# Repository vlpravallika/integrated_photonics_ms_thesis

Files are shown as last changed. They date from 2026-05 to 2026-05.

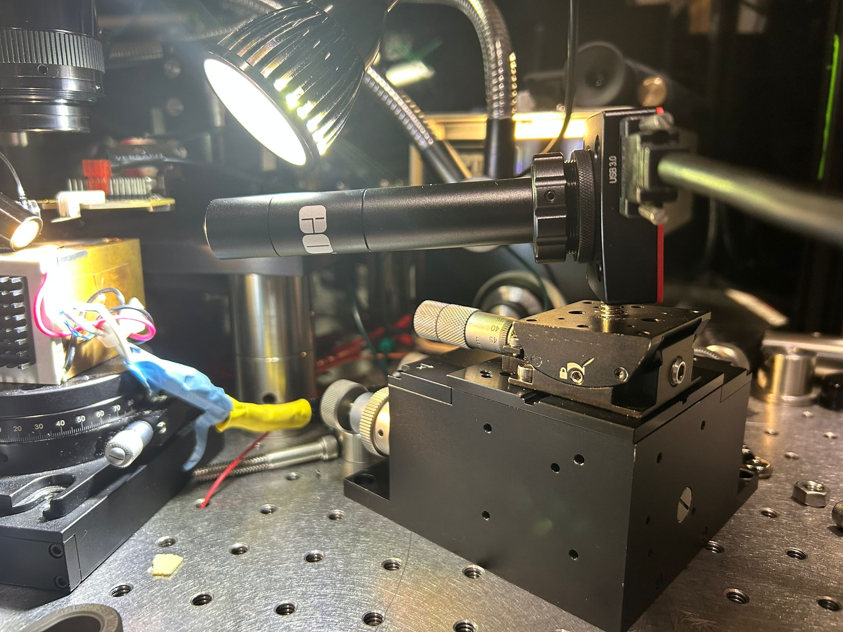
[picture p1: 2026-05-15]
Project_1_On_Chip_Detection/Images/setup_lens_camera_nanomax_goniometer.jpeg

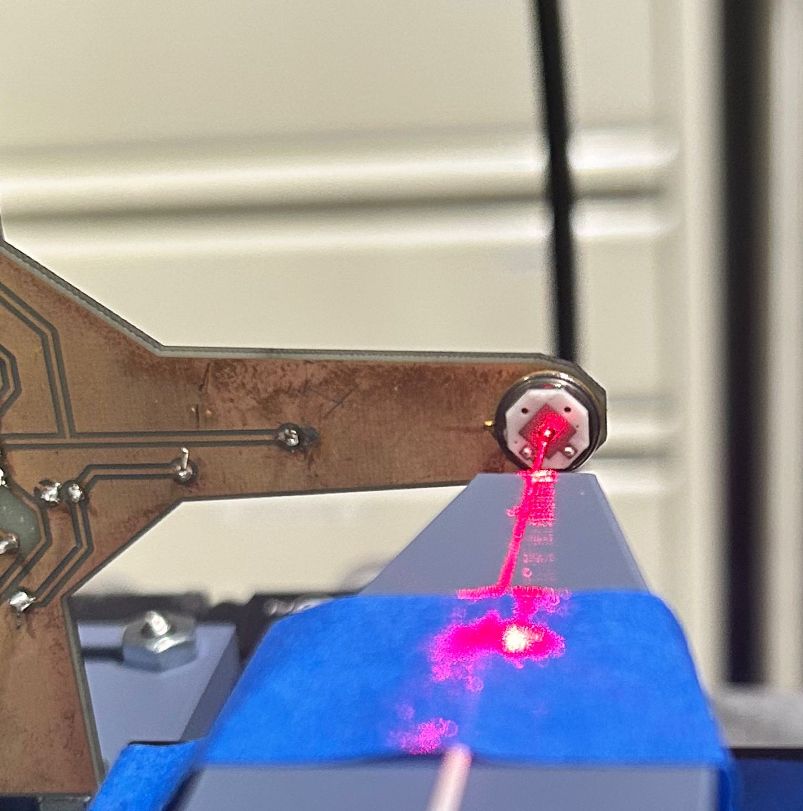
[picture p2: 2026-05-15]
Project_1_On_Chip_Detection/Images/setup_red_light_zoom.jpeg

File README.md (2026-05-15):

# Device Exploration for On-Chip Detection on Lithium Niobate and Amplification on Silicon for Scalable Integrated Photonics

**Vemparala Lakshmi Pravallika**  
B.Tech., Indian Institute of Technology Bombay (2024)  

Program in Media Arts and Sciences, School of Architecture and Planning  
Massachusetts Institute of Technology  

Master of Science in Media Arts and Sciences · submitted **15 May 2026**  

**Thesis supervisor:** Dirk Englund — Professor of Electrical Engineering and AI + Decision-making, MIT EECS  
**Committee:** Dirk Englund, Joseph Paradiso, Jelena Notaros  

**Committee certification page title (longer variant):** *Device Exploration for High-Efficiency On-Chip Detection in TFLN and Heterogeneous Gain Integration on Si for Scalable Integrated Photonics*  

The **citation copy** of the thesis is the **MIT-submitted document** (Libraries / program deposit). This Git directory holds **artifacts only** (CAD interchange, notebooks, code, CSV measurements).

---

## Abstract (as submitted)

Passive photonic integrated circuits excel at routing and modulating light, but generation and detection still rely on heterogeneous integration of foreign active materials. Bonding, epitaxy, flip-chip, and micro-transfer printing dominate how industry and research labs attach III–V detectors, amplifiers, and lasers to substrate hosts. An important bottleneck is the active–passive interface: coupling efficiency, alignment, and yield.

This thesis contributes two complementary demonstrations on leading passive platforms. Project 1 targets efficient telecom-band photodetection on thin-film lithium niobate. Lithographic adiabatic tapers to an absorber are the established route; here a doubly-clamped rib waveguide is selectively underetched and buckled so that a mechanical air gap drives the same adiabatic transition. Modeling predicts waveguide-to-absorber coupling near unity and total quantum efficiency near ninety-six percent for the coupled-mode design. A fiber-coupled test bench was built to characterize transmission and to separate the evanescent path from parasitic paths; a successor layout will suppress the dominant parasitic channel by geometry.

Project 2 targets optical gain on silicon using micro-transfer printing: a GaAs quantum-dot nanobeam with a 1D photonic-crystal cavity is placed on a silicon taper so that the signal transfers vertically to the III–V and is amplified by donor material. The workflow from donor release through stamp alignment and confocal pump delivery was implemented end-to-end, with several chiplets aligned within the taper tolerance for follow-on characterization.

Taken together, the work advances reusable recipes for high-efficiency detection on TFLN and compact gain on silicon spanning coherent links, switches, sensing, and integrated nonlinear and quantum photonics.

---

## What this repository contains

This tree is the **working artifact bundle** for the thesis hardware chapters: **SolidWorks / STEP digital twins** for both benches, **GDSFactory** mask notebooks, **COMSOL** project locks (models may be kept locally), **Tidy3D** mode notebooks and scripts, **Chip 1** detector-linearity checks, and **Chip 2** loopback **wavelength–power CSV archives** plus Python reduction and plotting.

There is **no separate folder named `transmission results`**: the **transmission sweep results** are the **`sweep_*.csv`** files (and derived **`summary_*.csv`**) under **`Chip 2 measurements/sweep 16 waveguides transmission/`**.

---

## Indexed layout (files that exist in this directory)

### `on chip detection setup solidworks model/`

**Project 1** mechanical **digital twin** geometry in neutral **STEP/STP** interchange (import into SolidWorks or any MCAD viewer). This is the same class of assembly the thesis documents in **§3.2.1** and **Fig. 3.4** (fiber-coupled detector bench with horizontal side-view imaging, clearance checks before 3D-printed fixtures).

| File | Role |
|---|---|
| `fiber array holder 15_01.STEP` | Custom **fiber-array holder** solid exported from SolidWorks (15 Jan revision in filename). |
| `Newport-TSX-1D.stp` | Newport **TSX-1D** linear stage vendor solid. |
| `B1818F-Step.step` | Thorlabs **B1818F** breadboard / plate geometry. |
| `MAX313D-Step.step` | Thorlabs **MAX313D** mount solid. |
| `TTR001-Step.step` | Thorlabs **TTR001** rotation mount solid. |
| `GPXL1-Step.step` | Thorlabs **GPXL1** goniometric stage solid. |
| `PR01-Step.step` | Thorlabs **PR01** cage plate solid. |
| `HFV002-Step.step` | Thorlabs **HFV002** vertical translation stage solid. |
| `CS165MU-Step.step` | Thorlabs **CS165MU** post / pedestal solid. |
| `step_63744.step` | Additional interchange solid from the same export set (SolidWorks default `step_*.step` naming). |

### `Topchip gain integration setup digital twin/`

| File | Role |
|---|---|
| `step_88206.step` | **Project 2** bench **STEP** export: silicon host with **dual edge-coupled fiber stacks** and **vertical confocal microscope** access as laid out in **§3.4.4–3.4.5** of the thesis (stamp alignment and pump delivery geometry). |

### `GDS/`

| File | Role |
|---|---|
| `loopback chip iteration 4.ipynb` | **Primary** **GDSFactory** notebook (generic PDK): **0.8 µm** strip waveguide, **127 µm** facet pitch, Euler **U-turn** radius `(PITCH/2)−5.8` µm, long routing straights, **`ETCH_LENGTHS` × `ETCH_WIDTHS` × `ETCH_GAPS`** etch-window sweep, layer pair `(1,0)` waveguide / `(2,0)` box. This is the **Chip 2** loopback mask lineage behind **Fig. 3.11** in the thesis. |
| `loopback chip iteration 3.ipynb` | **Earlier** loopback notebook (`repeats = 7`, **5000 µm** straight sections, etch lengths up to **2500 µm**, boolean / `LayerStack` tooling) retained for iteration history. |
| `bend_radius_analysis.ipynb` | **Tidy3D**-invoking bend / propagation study notebook (see notebook for exact solver calls and warnings). Informs Euler bend radius choices in the loopback notebooks. |

### `COMSOL Sim/`

| File | Role |
|---|---|
| `strip waveguide compressed.mph.lock` | Lock file for the **strip waveguide** COMSOL model (`strip waveguide compressed.mph` when saved locally). |
| `taper waveguide edge.mph.lock` | Lock file for the **taper / facet-edge** waveguide model (`taper waveguide edge.mph` when saved locally). |

Only **`.mph.lock`** files are present in this snapshot; the binary **`.mph`** models are usually excluded from Git for size. Re-open the corresponding `.mph` in COMSOL on a machine that has the full file.

### `Mode simulations/`

Eigenmode and overlap work for the **LNOI rib** cross section at **1550 nm** scale (thesis **Fig. 3.2** class: Tidy3D FDE rib mode).

| Path | Role |
|---|---|
| `ln_rib_mode_overlap.ipynb` | Notebook pipeline for **rib eigenmodes** and **overlap integrals** with a cleaved **SMF-28** Gaussian (**MFD = 10.4 µm**). |
| `edge_coupler.ipynb` | Notebook for **edge-coupler** field / coupling studies. |
| `rib waveguide modes.py` | Standalone **Tidy3D** `ModeSolver` script: **10 µm** SiO₂ underclad, **0.30 µm** LN film, **0.10 µm** slab, **0.20 µm** rib height, **0.80 µm** rib top width, **5.6 µm** bottom width; computes mode fields and **power overlap** with fiber mode. |
| `.vscode/settings.json` | Workspace editor settings used while developing these notebooks. |
| `build/log/.wsport.log` | Tool-generated log from a local solve / IDE session. |

### `Chip 1/`

| File | Role |
|---|---|
| `characterisation of detector comparison.py` | **Capped vs. uncapped** photoreceiver comparison: hard-coded **`power_dbm_*`** vs **`voltage_v_*`** arrays, plots **dBm** and **µW** vs voltage and inferred **photocurrent**; writes **`compare_dBm_vs_voltage.png`**, **`compare_uW_vs_voltage.png`**, **`compare_current_vs_voltage.png`** in the current working directory when run. Supports the **TIA / saturation** discussion around **Fig. 3.14** bench checkout. |

### `Chip 2 measurements/`

**Thesis linkage:** **§3.3.5** (measurement protocol), **§4.1.2–4.1.4** (contamination, operating wavelength, 2D free-space model). **Chip 2** has **25** designed loopbacks; **16** cleaved to viable facets (**§3.3.5** text). **Configuration 1** = angled facets; **Configuration 2** = parallel facets (**§3.3.5**). Sweeps run **1480–1600 nm**, **0 dBm** input; **~1595 nm** adopted as common operating point (**§4.1.3**, **Fig. 4.2**).

| Path | Role |
|---|---|
| `sweep 16 waveguides transmission/sweep_*.csv` | Raw **wavelength sweep** logs: columns include **`wavelength_nm`** and **`power_dBm`** (after instrument export). Filename grammar after cleanup: `sweep_<structure>_<YYYYMMDD>_<HHMMSS>.csv` for **Configuration 1** runs and `sweep_<structure>_p_<YYYYMMDD>_<HHMMSS>.csv` when `_p_` marks **Configuration 2** (“parallel facets”) reruns. |
| `sweep 16 waveguides transmission/summary_selected.csv` | Per-structure, per-orientation **max power** table produced by **`transmission_calculation.py`**. |
| `sweep 16 waveguides transmission/summary_maxima_selected.csv` | Alternate / intermediate maxima summary from the same script family. |
| `sweep 16 waveguides transmission/summary_maxima.csv` | Broader maxima table prior to orientation filtering (same analysis lineage). |
| `sweep 16 waveguides transmission/transmission_calculation.py` | **(1)** Regex-based batch **rename** of `sweep_*.csv` to the canonical patterns above (collision-safe). **(2)** **pandas**/**numpy** pass: filters structures **`{3,7,8,9,10}`**, finds **argmax** of `power_dBm`, deduplicates by structure+orientation, writes **`summary_selected.csv`** and **`wavelength_vs_structure_selected.png`**. |
| `transmission variation in fiber x.py` | Standalone **matplotlib** plots of **detector voltage vs. fiber \(x\)** (µm) from embedded arrays: raw trace, min–max scaled, and **20·log₁₀(V/Vmax)** dB scale—used for **lateral alignment** sweeps in the same measurement campaign as **§4.1.4**. |
| `Plots/Transmisison values for all 16 loopbacks comparison.py` | **Agg** backend: plots **all 16** structures’ **dBm** values at **1595 nm**, **0 dBm** input for **Case 1** vs **Case 2** arrays (same physical content as **Configuration 1** vs **2** in the thesis), highlights structures **3,7,8,9,10**, draws **−28 dBm** and **−65 dBm** reference lines. **You must edit `out_path`** inside the script before saving figures on a new machine. |

### `README.md`

This file.

---

## How measurements map to thesis language

- **Thesis:** **Configuration 1** (angled interfaces) vs **Configuration 2** (parallel interfaces).  
- **Python in this repo:** often labeled **Case 1** / **Case 2** in comments and plot legends.

---

## Dependencies (by component)

| Component | Typical stack |
|---|---|
| `GDS/*.ipynb` | **Python 3.10+**, **`gdsfactory`**, Jupyter |
| `Mode simulations/*` | **`tidy3d`**, **`numpy`**, **`matplotlib`**, Jupyter |
| `COMSOL Sim` | **COMSOL Multiphysics** (version matched to your `.mph`) |
| `Chip 2 measurements/*.py` | **`numpy`**, **`matplotlib`**; **`transmission_calculation.py`** analysis cell needs **`pandas`** |
| CAD | Any STEP/STP-capable viewer (SolidWorks, Onshape, FreeCAD) |

---

## Suggested reproduction order

1. Open STEP files in **`on chip detection setup solidworks model/`** and **`Topchip gain integration setup digital twin/`** to recover full 3D clearance context (**Fig. 3.4** and Project 2 bench figures).  
2. Run **`GDS/loopback chip iteration 4.ipynb`**, then compare against **`loopback chip iteration 3.ipynb`** for design deltas.  
3. Run **`bend_radius_analysis.ipynb`** if updating bend radii before a mask rerun.  
4. Execute **`Mode simulations/rib waveguide modes.py`** or the notebooks after configuring **Tidy3D** credentials.  
5. Open COMSOL **`.mph`** files that pair with the two **`.mph.lock`** names (local machine).  
6. From **`Chip 2 measurements/sweep 16 waveguides transmission/`**, run **`transmission_calculation.py`** (rename pass only when ingesting new raw sweeps), then run the **`Plots/`** script after fixing paths.

---

## Version control hygiene (recommended)

Add to **`.gitignore`** if you expand commits: `*.mph.lock`, `**/.vscode/`, `**/build/`, large `*.mph`, and any regenerated **`compare_*.png`** / **`transmission_vs_structure.png`** outputs if you do not want binaries in history.

---

## License

Thesis text and figures: © **2026** Vemparala Lakshmi Pravallika (subject to MIT thesis deposit terms). **Vendor STEP** models remain property of their respective suppliers. **Tidy3D**, **COMSOL**, **gdsfactory**, and Python packages follow their own licenses.

---

## Contact

Use the correspondence channels listed in the submitted thesis front matter.

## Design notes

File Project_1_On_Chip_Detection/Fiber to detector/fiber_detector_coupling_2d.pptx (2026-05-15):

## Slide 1

Fiber-to-Detector 2D Coupling: Model & Concepts

Geometry
SMF-28 fiber emits along +x; detector active face points -z (downward)
Only diverging rays from the Gaussian tail reach the detector
2D cross-section in the x-z plane; detector length = 1 mm
Factors in the Model
1. Gaussian beam angular profile G(th) = exp(-2 th^2 / th0^2)
2. Snell refraction at fiber exit (n_core > n_air -> beam widens)
3. Fresnel transmission at fiber exit (glass -> air interface)
4. Geometric angular aperture (which angles hit the detector)
5. Fresnel transmission at detector (air -> InGaAs, angle-dependent)
Coupling Fraction
eta = Integral of [ G * T_fiber * T_detector ] over detector angles
divided by total Gaussian power in forward half-space
Each factor is evaluated at every angle — not a single average

Dominant Loss Mechanisms
1. Gaussian falloff (dominant)
Intensity drops exponentially off-axis
At th0: 13.5% of peak
At 2*th0: 0.03% of peak
2. Fresnel loss at detector
High index mismatch (n=1 -> n=3.5)
Near-grazing incidence in this geometry
Transmittance 40-60% at typical angles
3. Fresnel loss at fiber exit
Glass-to-air reflection (~3.6%)
Relatively minor compared to above two

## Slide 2

How Position Affects Coupling (x, z Dependence)

Vertical distance z (dominant)
Larger z -> steeper angle from fiber axis
Steeper angle -> deeper into Gaussian tail -> exponentially less power
Also: steeper angle -> more grazing on detector -> higher Fresnel loss
z is the single most critical parameter
Horizontal distance x
Larger x -> ray angle to detector center decreases (closer to axis)
-> more Gaussian intensity available
But also: larger x -> detector subtends smaller angular range
-> captures less of the beam
Trade-off: optimal x exists for each z
Combined behavior
Best coupling at small z and moderate x
Coupling falls off exponentially with z, logarithmically with x mismatch

Physical Picture
The Gaussian beam is a narrow cone:
most power within ~5 deg of axis.
Moving detector UP (larger z):
-> requires light at steeper angles
-> exponential intensity drop
-> worse Fresnel at detector
Moving detector RIGHT (larger x):
-> shallower angle (more intensity)
-> but narrower angular aperture
-> net effect: diminishing returns
Best 2D coupling: ~4-5%
(-13 to -15 dBm for 0 dBm input)
at z ~ 100-200 um, x ~ 2000-4000 um

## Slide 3

Detector & Waveguide Placement: Safe from Stray Light

Placement Strategy
All waveguides and detector must lie outside the 2*th0 emission cone
2*th0 = 10.9 deg contains 99.97% of beam power (only 0.03% beyond)
Additional 500 um safety margin in lateral (y) direction
Waveguide Loopback
Lateral shift y = cone height at arm end + 500 um margin
Arm length 7000 um | pitch 127 um | all arms above the cone
Detector (1 mm diameter, parallel to chip)
Placed at min. clearance position: 500 um inside WG end, 500 um above cone
Angle from fiber axis to detector center: 15.1 deg >> 2*th0 = 10.9 deg
Gaussian intensity at detector: < 10^-7 of peak
Coupled power: < -80 dBm (effectively zero stray light)
Verification Summary
Detector center well outside beam cone (15 deg vs 11 deg boundary)
Waveguides entirely beyond 2*th0 + 500 um margin
No fiber stray light interferes with detector or waveguide etch region
Safe for detector operation without additional shielding

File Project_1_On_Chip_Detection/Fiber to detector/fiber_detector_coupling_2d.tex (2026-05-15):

% ======================================================================
% Paste this section into your existing document.
% Required packages (add to your preamble if not already present):
%   \usepackage{amsmath,amssymb}
%   \usepackage{physics}        % for \dd
%   \usepackage{siunitx}        % for SI units
%   \usepackage{booktabs}       % for tables
%   \usepackage{enumitem}       % for custom lists
% ======================================================================

\section{2D Gaussian Beam Coupling: SMF-28 Fibre to Side-Facing InGaAs Detector}

% ----------------------------------------------------------------------
\subsection{Problem Geometry}
% ----------------------------------------------------------------------

Consider a single-mode fibre (Corning SMF-28) with its cleaved end-face
oriented so that the fibre axis is horizontal (the $+x$~direction).
An InGaAs photodetector of length $d = \SI{1}{\milli\metre}$ is placed
above the fibre tip with its active surface facing \emph{vertically
downward} (the $-z$~direction).  The detector centre is located at
horizontal distance~$x_c$ and vertical distance~$z_\mathrm{det}$ from
the fibre tip.

In this 2D analysis (cross-section in the $xz$-plane), the fibre emits
a Gaussian beam into the forward half-space.  Only a small fraction of
this light propagates at a steep enough angle to intercept the detector,
and that fraction is further reduced by Fresnel reflections at two
interfaces:
%
\begin{enumerate}[label=(\roman*)]
  \item the fibre end-face (glass $\to$ air), and
  \item the detector active surface (air $\to$ InGaAs).
\end{enumerate}

% ----------------------------------------------------------------------
\subsection{Key Parameters}
% ----------------------------------------------------------------------

\begin{center}
\begin{tabular}{@{}llll@{}}
\toprule
\textbf{Symbol} & \textbf{Description} & \textbf{Value} & \textbf{Unit} \\
\midrule
$\lambda$       & Free-space wavelength        & 1.550  & \si{\micro\metre} \\
$w_0$           & Beam waist (MFD/2)           & 5.2    & \si{\micro\metre} \\
$n_\text{core}$ & Fibre core index (@\SI{1550}{\nano\metre}) & 1.4682 & -- \\
$n_\text{air}$  & Air refractive index         & 1.0    & -- \\
$n_\text{det}$  & InGaAs detector index (@\SI{1550}{\nano\metre}) & 3.5 & -- \\
$d$             & Detector length              & 1.0    & \si{\milli\metre} \\
\bottomrule
\end{tabular}
\end{center}

\noindent
The mode-field diameter (MFD) of SMF-28 at \SI{1550}{\nano\metre} is
approximately \SI{10.4}{\micro\metre}, giving a beam waist
$w_0 = \text{MFD}/2 = \SI{5.2}{\micro\metre}$.

% ----------------------------------------------------------------------
\subsection{Gaussian Beam Divergence}
% ----------------------------------------------------------------------

\subsubsection{Divergence inside the fibre}

A Gaussian beam with waist $w_0$ propagating in a medium of refractive
index $n$ has a far-field $1/e^2$ half-angle divergence given by
%
\begin{equation}\label{eq:theta-fib}
  \theta_\text{fib}
  = \frac{\lambda}{\pi\, n_\text{core}\, w_0}.
\end{equation}
%
Substituting the values:
%
\begin{equation}
  \theta_\text{fib}
  = \frac{1.550 \times 10^{-6}}
         {\pi \times 1.4682 \times 5.2 \times 10^{-6}}
  \approx 0.0646~\text{rad}
  \approx 3.70^\circ.
\end{equation}

\subsubsection{Snell's refraction at the flat fibre end-face}
\label{sec:snell}

The fibre has a flat, cleaved end-face that acts as a planar dielectric
interface between the fibre core (index $n_\text{core}$) and air
(index $n_\text{air}$).  When a ray at angle $\theta_\text{fib}$
(measured from the fibre axis, i.e.\ the surface normal of the end-face)
exits the fibre, Snell's law governs the refracted angle:
%
\begin{equation}\label{eq:snell}
  \boxed{%
    n_\text{core}\,\sin\theta_\text{fib}
    = n_\text{air}\,\sin\theta_0
  }
\end{equation}
%
Since $n_\text{core} > n_\text{air}$, the refracted angle $\theta_0$
is \emph{larger} than $\theta_\text{fib}$: the beam fans out more
in air than it did inside the glass.  Solving for $\theta_0$:
%
\begin{equation}\label{eq:theta0}
  \theta_0
  = \arcsin\!\left(\frac{n_\text{core}}{n_\text{air}}
    \sin\theta_\text{fib}\right)
  = \arcsin\!\bigl(1.4682 \times \sin 3.70^\circ\bigr)
  \approx 5.44^\circ.
\end{equation}

\paragraph{Physical intuition.}
Light travels slower in glass (higher index) than in air.  At the flat
interface, the tangential component of the wavevector is conserved;
consequently the ray bends \emph{away} from the surface normal when
passing from a denser to a less dense medium.  The divergence
half-angle increases from $3.70^\circ$ to $5.44^\circ$.

% ----------------------------------------------------------------------
\subsection{Gaussian Angular Intensity Profile}
% ----------------------------------------------------------------------

In the far field, the angular intensity distribution of the Gaussian
beam (in air) is itself a Gaussian:
%
\begin{equation}\label{eq:gaussian}
  \boxed{%
    G(\theta) = \exp\!\left(-\frac{2\,\theta^2}{\theta_0^2}\right)
  }
\end{equation}
%
where $\theta$ is the angle of a given ray measured from the fibre axis,
and $\theta_0$ is the $1/e^2$ divergence half-angle in air
(Eq.~\ref{eq:theta0}).

\paragraph{Why the factor of 2?}
The electric \emph{field} amplitude falls as
$E(\theta) \propto \exp(-\theta^2/\theta_0^2)$.
Since intensity (power per unit angle in 2D) is proportional to
$|E|^2$, the intensity profile acquires twice the exponent:
$I \propto \exp(-2\theta^2/\theta_0^2)$.

\paragraph{Key values of $G(\theta)$:}
\begin{center}
\begin{tabular}{@{}lcc@{}}
\toprule
\textbf{Angle} & $G(\theta)$ & \textbf{Meaning} \\
\midrule
$\theta = 0$         & $1.000$        & On-axis (peak) \\
$\theta = \theta_0$  & $e^{-2} \approx 0.135$ & $1/e^2$ point; 13.5\% of peak \\
$\theta = 2\theta_0$ & $e^{-8} \approx 3.4\times10^{-4}$ & 0.03\% of peak \\
$\theta = 3\theta_0$ & $e^{-18}\approx 1.5\times10^{-8}$ & Essentially zero \\
\bottomrule
\end{tabular}
\end{center}

\noindent
The Gaussian drops \emph{extremely} rapidly with angle.  Since the
detector is placed off-axis (above the fibre), only rays in the tail of
the Gaussian distribution reach it, which is the dominant reason that
coupling is low in this side-fire geometry.

% ----------------------------------------------------------------------
\subsection{Fresnel Reflection and Transmission}
% ----------------------------------------------------------------------

At each dielectric interface, a fraction of the incident light is
reflected and the remainder is transmitted.  The reflectance depends on
the angle of incidence~$\theta_i$, the refractive indices $n_1$
(incident medium) and $n_2$ (transmitted medium), and the polarisation.

\subsubsection{Fresnel equations}

Using Snell's law to obtain the transmitted angle,
%
\begin{equation}
  \cos\theta_t = \sqrt{1 - \left(\frac{n_1}{n_2}\right)^2 \sin^2\theta_i},
\end{equation}
%
the amplitude reflection coefficients for \textbf{s}-polarisation (TE)
and \textbf{p}-polarisation (TM) are:
%
\begin{align}
  r_s &= \frac{n_1\cos\theta_i - n_2\cos\theta_t}
              {n_1\cos\theta_i + n_2\cos\theta_t},
  \label{eq:rs} \\[6pt]
  r_p &= \frac{n_2\cos\theta_i - n_1\cos\theta_t}
              {n_2\cos\theta_i + n_1\cos\theta_t}.
  \label{eq:rp}
\end{align}

\subsubsection{Power transmittance}

For unpolarised light (a reasonable assumption for a single-mode fibre
with no polarisation-maintaining structure), the average \textbf{power
transmittance} is:
%
\begin{equation}\label{eq:fresnel-T}
  \boxed{%
    T(\theta_i;\, n_1, n_2)
    = 1 - \frac{r_s^2 + r_p^2}{2}
  }
\end{equation}

\paragraph{Note on total internal reflection.}
When $n_1 > n_2$ (e.g.\ glass $\to$ air), if $\theta_i$ exceeds the
critical angle $\theta_c = \arcsin(n_2/n_1)$, the term under the
square root for $\cos\theta_t$ becomes negative, and \emph{all} light
is reflected ($T = 0$).  For the fibre exit face,
$\theta_c = \arcsin(1/1.4682) \approx 42.9^\circ$.  In practice, the
Gaussian beam has negligible power beyond $\sim\!3\theta_0 \approx
16^\circ$, so total internal reflection is not a concern.

\subsubsection{Interface 1: Fibre exit face (glass $\to$ air)}

At the fibre end-face, the incidence angle on the surface is $\theta$
(the same angle measured from the fibre/surface normal).  Thus:
%
\begin{equation}\label{eq:T-fib}
  T_\text{fib}(\theta) = T(\theta;\; n_\text{core},\; n_\text{air}).
\end{equation}
%
At normal incidence ($\theta = 0$):
%
\begin{equation}
  T_\text{fib}(0)
  = 1 - \left(\frac{n_\text{core} - n_\text{air}}
                    {n_\text{core} + n_\text{air}}\right)^{\!2}
  = 1 - \left(\frac{1.4682 - 1}{1.4682 + 1}\right)^{\!2}
  \approx 0.964.
\end{equation}
%
This means ${\sim}3.6\%$ of the on-axis power is reflected back into
the fibre at the exit face.

\subsubsection{Interface 2: Detector surface (air $\to$ InGaAs)}

The detector active surface is oriented vertically (facing downward,
perpendicular to the fibre axis).  A ray travelling at angle $\theta$
from the fibre axis strikes the detector surface at an incidence angle
of:
%
\begin{equation}\label{eq:det-angle}
  \theta_\text{inc,\,det} = \frac{\pi}{2} - \theta.
\end{equation}
%
This is because the detector normal is horizontal (along $-x$), while
the ray direction makes angle $\theta$ with the horizontal.
Therefore:
%
\begin{equation}\label{eq:T-det}
  T_\text{det}(\theta) = T\!\left(\frac{\pi}{2} - \theta;\;
    n_\text{air},\; n_\text{det}\right).
\end{equation}
%
\paragraph{Grazing incidence problem.}
For small $\theta$ (rays close to the fibre axis),
$\theta_\text{inc,\,det} \approx 90^\circ$, which is \emph{grazing
incidence}.  Fresnel reflectance approaches 100\% at grazing angles
for any dielectric interface.  Even at moderate angles, e.g.\
$\theta = 10^\circ$ gives $\theta_\text{inc,\,det} = 80^\circ$,
the transmittance is significantly reduced.

At normal incidence on the detector ($\theta_\text{inc,\,det} = 0$):
%
\begin{equation}
  T_\text{det}\big|_\text{normal}
  = 1 - \left(\frac{n_\text{air} - n_\text{det}}
                    {n_\text{air} + n_\text{det}}\right)^{\!2}
  = 1 - \left(\frac{1 - 3.5}{1 + 3.5}\right)^{\!2}
  \approx 0.691.
\end{equation}
%
Even at normal incidence, ${\sim}30.9\%$ of the light is reflected due
to the high refractive index of InGaAs.  At the typical incidence angles
in this geometry (\SIrange{75}{88}{\degree}), the transmittance drops
to roughly $40$--$60\%$.

% ----------------------------------------------------------------------
\subsection{Detector Geometry and Angular Limits}
% ----------------------------------------------------------------------

The detector of length $d$ is centred at horizontal position $x_c$
and height $z_\text{det}$.  Its left and right edges are at:
%
\begin{equation}
  x_L = x_c - \frac{d}{2}, \qquad x_R = x_c + \frac{d}{2}.
\end{equation}

From the fibre tip (the origin), the angle subtended by each edge is:
%
\begin{align}
  \theta_\text{min} &= \arctan\!\left(\frac{z_\text{det}}{x_R}\right),
  \label{eq:thmin} \\
  \theta_\text{max} &= \arctan\!\left(\frac{z_\text{det}}{x_L}\right).
  \label{eq:thmax}
\end{align}
%
These are the minimum and maximum angles (from the fibre axis) at which
a ray from the fibre tip can strike the detector.  The angular range
$[\theta_\text{min},\, \theta_\text{max}]$ defines the integration
limits for the coupling integral.

\paragraph{Edge cases.}
If $x_L \leq 0$ (detector extends behind the fibre tip), then
$\theta_\text{max} = \pi/2$.  If $x_R \leq 0$, the detector is
entirely behind the fibre and no forward-emitted light can reach it.

% ----------------------------------------------------------------------
\subsection{Coupling Integral}
% ----------------------------------------------------------------------

\subsubsection{Integrand}

At each angle $\theta \in [\theta_\text{min},\,\theta_\text{max}]$,
the differential contribution to the captured power includes three
multiplicative factors:
%
\begin{enumerate}[label=\arabic*.]
  \item \textbf{Gaussian intensity} $G(\theta)$: how much power the
        fibre emits in direction $\theta$.
  \item \textbf{Fresnel transmission at fibre exit} $T_\text{fib}(\theta)$:
        fraction transmitted through the glass--air interface.
  \item \textbf{Fresnel transmission at detector} $T_\text{det}(\theta)$:
        fraction transmitted into the InGaAs at the angle of incidence
        $\pi/2 - \theta$.
\end{enumerate}
%
The integrand is therefore:
%
\begin{equation}\label{eq:integrand}
  \boxed{%
    f(\theta)
    = G(\theta)\;\cdot\;T_\text{fib}(\theta)\;\cdot\;T_\text{det}(\theta)
    = \exp\!\left(-\frac{2\theta^2}{\theta_0^2}\right)
      \cdot T(\theta;\,n_\text{core},n_\text{air})
      \cdot T\!\left(\tfrac{\pi}{2}-\theta;\,n_\text{air},n_\text{det}\right).
  }
\end{equation}

\paragraph{Angle-dependent integration.}
Crucially, the Fresnel transmittances are evaluated at \emph{every}
angle $\theta$ within the integration range---not at a single
representative angle.  This is important because both $T_\text{fib}$
and $T_\text{det}$ vary significantly across the angular aperture of
the detector.

\subsubsection{Normalisation}

The total power emitted by the fibre into the forward half-space
(in 2D) is proportional to:
%
\begin{equation}\label{eq:Ptot}
  P_\text{tot} = \int_{-\pi/2}^{+\pi/2}
    G(\theta)\;\dd{\theta}
  = \int_{-\pi/2}^{+\pi/2}
    \exp\!\left(-\frac{2\theta^2}{\theta_0^2}\right)\dd{\theta}.
\end{equation}
%
Note that $P_\text{tot}$ does \emph{not} include the Fresnel loss at
the fibre exit.  This is because we define the coupling fraction
relative to the power \emph{inside} the fibre (i.e.\ the input power).
The Fresnel losses are accounted for in the numerator.

\subsubsection{Captured power and coupling fraction}

The power captured by the detector is:
%
\begin{equation}\label{eq:Pdet}
  P_\text{det} = \int_{\theta_\text{min}}^{\theta_\text{max}}
    f(\theta)\;\dd{\theta}
  = \int_{\theta_\text{min}}^{\theta_\text{max}}
    G(\theta)\;T_\text{fib}(\theta)\;T_\text{det}(\theta)\;\dd{\theta}.
\end{equation}
%
The coupling fraction is:
%
\begin{equation}\label{eq:eta}
  \boxed{%
    \eta = \frac{P_\text{det}}{P_\text{tot}}
         = \frac{\displaystyle
           \int_{\theta_\text{min}}^{\theta_\text{max}}
           G(\theta)\;T_\text{fib}(\theta)\;T_\text{det}(\theta)
           \;\dd{\theta}}
           {\displaystyle
           \int_{-\pi/2}^{+\pi/2}
           G(\theta)\;\dd{\theta}}
  }
\end{equation}
%
and the coupled power in \si{\decibel m} for an input of \SI{0}{\decibel m}
is:
%
\begin{equation}\label{eq:dBm}
  P\;[\si{\decibel m}] = 10\,\log_{10}(\eta).
\end{equation}

% ----------------------------------------------------------------------
\subsection{Loss Mechanisms}
% ----------------------------------------------------------------------

The total coupling loss can be understood as a product of three
independent loss factors, each of which reduces the captured power:

\subsubsection{Gaussian beam falloff (dominant)}

The fibre emits most of its power within a narrow cone of half-angle
$\theta_0 \approx 5.4^\circ$ around the axis.  The detector, positioned
above and to the side of the fibre, subtends angles typically in the
range $3^\circ$--$15^\circ$.  At these angles, the Gaussian intensity
$G(\theta) = \exp(-2\theta^2/\theta_0^2)$ is already very small:
%
\begin{itemize}
  \item At $\theta = \theta_0$: $G = e^{-2} \approx 0.135$ (13.5\%
        of peak).
  \item At $\theta = 2\theta_0 \approx 10.9^\circ$:
        $G = e^{-8} \approx 3.4 \times 10^{-4}$ (0.03\%).
  \item At $\theta = 3\theta_0 \approx 16.3^\circ$:
        $G = e^{-18} \approx 1.5 \times 10^{-8}$ (effectively zero).
\end{itemize}
%
This exponential falloff is the \emph{primary} reason for low coupling
in this geometry.  Moving the detector further from the axis (larger
$\theta_\text{min}$) causes an exponential decrease in captured power.

\subsubsection{Fresnel loss at fibre exit ($\sim$3.6\%)}

At the glass-to-air interface, about 3.6\% of the power is reflected
at normal incidence.  This loss increases slightly at larger angles but
remains modest ($< 10\%$) for all angles where the Gaussian has
significant power ($\theta < 3\theta_0$).  This is a relatively minor
loss compared to the other two.

\subsubsection{Fresnel loss at detector (significant)}

The air-to-InGaAs interface has a large index mismatch
($n_\text{air} = 1.0$ vs.\ $n_\text{det} = 3.5$), resulting in high
reflectance even at normal incidence (${\sim}30.9\%$).  In this geometry,
the situation is much worse: rays from the fibre strike the detector at
near-grazing incidence ($\theta_\text{inc} = 75^\circ$--$88^\circ$),
where Fresnel reflectance is even higher.  Typical transmittance in this
angular range is only $40$--$60\%$, representing a loss of
${\sim}2$--\SI{4}{\decibel}.

The Brewster angle for this interface is:
\begin{equation}
  \theta_B = \arctan\!\left(\frac{n_\text{det}}{n_\text{air}}\right)
  = \arctan(3.5)
  \approx 74.1^\circ,
\end{equation}
at which $r_p = 0$ (no reflection for p-polarisation).  However, even
at Brewster's angle, the s-polarisation still reflects strongly, so the
unpolarised average transmittance remains well below unity.

% ----------------------------------------------------------------------
\subsection{Summary of the Calculation}
% ----------------------------------------------------------------------

The complete procedure for computing the coupled power fraction is:
%
\begin{enumerate}
  \item \textbf{Compute divergence angles.}
    Use Eq.~\eqref{eq:theta-fib} for $\theta_\text{fib}$ inside the
    fibre, then Snell's law (Eq.~\ref{eq:snell}) to obtain
    $\theta_0$ in air.

  \item \textbf{Determine geometric angular limits.}
    From the detector position $(x_c,\, z_\text{det})$ and length $d$,
    compute $\theta_\text{min}$ and $\theta_\text{max}$ using
    Eqs.~\eqref{eq:thmin}--\eqref{eq:thmax}.

  \item \textbf{Evaluate the coupling integral.}
    Numerically integrate Eq.~\eqref{eq:Pdet} over
    $[\theta_\text{min},\, \theta_\text{max}]$, where the integrand
    (Eq.~\ref{eq:integrand}) is the product of the Gaussian profile
    and the two angle-dependent Fresnel transmittances.

  \item \textbf{Normalise.}
    Divide by the total forward-hemisphere Gaussian integral
    (Eq.~\ref{eq:Ptot}) to obtain $\eta$.

  \item \textbf{Convert to \si{\decibel m}.}
    $P\;[\si{\decibel m}] = 10\log_{10}(\eta)$ for a \SI{0}{\decibel m}
    input.
\end{enumerate}

% ----------------------------------------------------------------------
\subsection{Numerical Results}
% ----------------------------------------------------------------------

Table~\ref{tab:results} presents the coupled power for selected detector
positions.  The detector is a \SI{1}{\milli\metre} InGaAs detector
centred at horizontal distance $x_c$ and height $z_\text{det}$ from the
fibre tip.

\begin{table}[h]
\centering
\caption{Coupled power to \SI{1}{\milli\metre} InGaAs detector
  (\SI{0}{\decibel m} input, 2D model).}
\label{tab:results}
\begin{tabular}{@{}rrrl@{}}
\toprule
$z$ [\si{\micro\metre}] & $x_c$ [\si{\micro\metre}]
  & Fraction & Power [\si{\decibel m}] \\
\midrule
100  & 1000 & $4.57\times10^{-19}$ & $-183.40$ \\
100  & 2000 & $3.85\times10^{-6}$  & $-54.14$  \\
100  & 3000 & $1.70\times10^{-3}$  & $-27.70$  \\
100  & 5000 & $3.22\times10^{-2}$  & $-14.92$  \\
500  & 1000 & $1.81\times10^{-4}$  & $-37.42$  \\
500  & 2000 & $3.67\times10^{-2}$  & $-14.36$  \\
500  & 3000 & $4.63\times10^{-2}$  & $-13.34$  \\
500  & 5000 & $2.48\times10^{-2}$  & $-16.06$  \\
1000 & 1000 & ${\sim}0$            & $-349.93$ \\
1000 & 3000 & $1.42\times10^{-9}$  & $-88.48$  \\
1000 & 5000 & $4.15\times10^{-5}$  & $-43.82$  \\
\bottomrule
\end{tabular}
\end{table}

\paragraph{Key observations.}
\begin{itemize}
  \item Coupling is extremely sensitive to geometry.  At
    $(z, x_c) = (100,\,1000)\;\si{\micro\metre}$, the coupling is
    $-183$\;\si{\decibel m} (essentially zero), because the detector
    subtends angles far into the Gaussian tail.
  \item Best coupling (${\sim}-13$\;\si{\decibel m}, about 4.6\%) is
    achieved around $(z, x_c) = (500,\,3000)\;\si{\micro\metre}$,
    where the detector falls near the $1/e^2$ edge of the beam.
  \item At large $z$ (e.g.\ \SI{1000}{\micro\metre}), coupling drops
    dramatically because the required propagation angle pushes deep into
    the Gaussian tail.
  \item Even in the best case, coupling is limited to a few percent
    due to the combination of geometric overlap, Fresnel losses at
    the fibre exit, and especially Fresnel losses at the near-grazing
    detector surface.
\end{itemize}

% ----------------------------------------------------------------------
\subsection{Assumptions and Limitations}
% ----------------------------------------------------------------------

\begin{enumerate}
  \item \textbf{2D model.}  This analysis considers only the
    cross-section in the $xz$-plane.  The beam also diverges in the
    $y$-direction, which would further reduce coupling in a full 3D
    calculation.

  \item \textbf{Far-field approximation.}  The angular Gaussian profile
    is valid in the far field.  For detectors very close to the fibre
    tip ($z \ll $ Rayleigh range $\approx \SI{130}{\micro\metre}$ in
    air), near-field effects would need to be considered.

  \item \textbf{Flat, uncoated surfaces.}  Both the fibre end-face and
    the detector surface are assumed to be flat and uncoated.  An
    anti-reflection (AR) coating on the detector could significantly
    reduce Fresnel losses and improve coupling by several~\si{\decibel}.

  \item \textbf{Unpolarised light.}  The SMF-28 fibre does not maintain
    polarisation, so an average of s- and p-polarisation Fresnel
    coefficients is used.

  \item \textbf{No absorption or scattering.}  Propagation losses in
    the short air gap are neglected.

  \item \textbf{Ideal Gaussian mode.}  The fibre output is assumed to be
    a perfect fundamental Gaussian mode with no higher-order content.
\end{enumerate}

% ----------------------------------------------------------------------
\subsection{Extension to 3D: Coupling at an Arbitrary Detector Position}
% ----------------------------------------------------------------------

The 2D model considers only the $xz$-plane.  In practice the detector may
also be offset laterally (in $y$).  For a circularly symmetric Gaussian
mode (as in SMF-28), the divergence angle $\theta_0$ is \emph{identical}
in all transverse directions, so the angular intensity profile generalises
to
%
\begin{equation}\label{eq:G3D}
  G(\theta) = \exp\!\left(-\frac{2\,\theta^2}{\theta_0^2}\right),
\end{equation}
%
where $\theta$ is now the \emph{total} angle from the fibre axis,
regardless of azimuthal orientation.  The 2D ``V''-shaped divergence
becomes a circular cone in 3D.

\subsubsection{3D coupling integral}

For a circular detector of radius $R_\text{det} = d/2$ centred at
$(x_d,\, y_d,\, z_d)$ with its active face pointing in the $-z$
direction (parallel to the chip plane), the coupled power fraction is:
%
\begin{equation}\label{eq:eta3D}
  \eta_{3\text{D}}
  = \frac{2}{\pi\,\theta_0^2}
    \iint_\text{det}\!
    G(\theta)\;\;
    T_\text{fib}(\theta)\;\;
    T_\text{det}(\alpha)\;\;
    \frac{\cos\alpha}{r^2}\;
    \dd{A},
\end{equation}
%
where for each point $(x, y, z_d)$ on the detector disc:
%
\begin{itemize}
  \item $r = \sqrt{x^2 + y^2 + z_d^2}$ is the distance from the fibre tip,
  \item $\theta = \arctan\!\bigl(\sqrt{y^2 + z_d^2}\,\big/\,x\bigr)$ is the
        angle from the fibre axis,
  \item $\alpha = \arccos(z_d / r)$ is the angle of incidence on the
        detector surface (the ray vs.\ the detector normal $-\hat{z}$),
  \item $T_\text{fib}(\theta)$ and $T_\text{det}(\alpha)$ are the
        Fresnel power transmittances (Eq.~\ref{eq:fresnel-T}) at the fibre
        exit and detector entry respectively,
  \item the factor $\cos\alpha / r^2$ converts the area element $\dd{A}$
        into a solid-angle element as seen from the fibre tip.
\end{itemize}
%
The prefactor $2/(\pi\theta_0^2)$ normalises the 3D Gaussian beam power
(small-angle approximation):
%
\begin{equation}
  P_\text{tot}
  = \int_0^{2\pi}\!\!\int_0^{\pi/2}
    G(\theta)\,\sin\theta\;\dd{\theta}\;\dd{\phi}
  \;\approx\; \frac{\pi\,\theta_0^2}{2}\;.
\end{equation}

\paragraph{Key difference from 2D.}
In 2D the beam spreads in one plane; in 3D it spreads into a full cone
($2\pi$ in azimuth), so the power per unit solid angle reaching an
off-axis detector is lower.  The angles $\theta_0$ and $2\theta_0$ are
\emph{unchanged}; only the integrated power fractions differ.

% ----------------------------------------------------------------------
\subsection{Detector and Waveguide Placement Verification}
\label{sec:placement}
% ----------------------------------------------------------------------

The waveguide loopback and detector must be placed outside the fibre
emission cone to avoid stray-light interference.  The placement rule is:
%
\begin{enumerate}
  \item Compute the $2\theta_0$ cone radius at the waveguide end
        ($x = \SI{7000}{\micro\metre}$):
        \[
          y_\text{cone} = x \tan(2\theta_0)
          = 7000 \times \tan(10.88^\circ)
          \approx \SI{1345}{\micro\metre}.
        \]
  \item Add a safety margin of \SI{500}{\micro\metre}:
        \[
          y_\text{WG} = y_\text{cone} + 500
          = \SI{1845}{\micro\metre}.
        \]
  \item The detector (1\,mm diameter) is centred at
        $(x_d, y_d, z_d) = (6500,\; 1750,\; 50)\;\si{\micro\metre}$,
        i.e.\ \SI{500}{\micro\metre} left of the waveguide end and
        \SI{500}{\micro\metre} above the $2\theta_0$ cone edge.
\end{enumerate}

\subsubsection{Numerical verification}

\begin{center}
\begin{tabular}{@{}lccl@{}}
\toprule
\textbf{Scenario} & \textbf{Fraction} & \textbf{dBm} & \textbf{Note} \\
\midrule
Min.\ clearance $(6500,\,1750,\,50)$ & $8.1\times10^{-9}$ & $-80.9$
  & Well outside cone \\
Directly above fibre $(6500,\,0,\,50)$ & $4.3\times10^{-4}$ & $-33.7$
  & On-axis, much higher \\
2D in-plane $(x\!=\!6500,\,z\!=\!50)$ & $5.5\times10^{-10}$ & $-92.6$
  & 2D model (no $y$ offset) \\
\bottomrule
\end{tabular}
\end{center}

\noindent
At the min-clearance position, the angle from the fibre axis to the
detector centre is $\theta \approx 15.1^\circ$, which exceeds
$2\theta_0 = 10.9^\circ$ by a wide margin.  The Gaussian intensity at
$15.1^\circ$ is only $2.2 \times 10^{-7}$ of the on-axis peak,
confirming that the stray-light contribution is negligible
($< -80\;\si{\decibel m}$).

\paragraph{Conclusion.}
Both the waveguide structures (lateral shift $y = \SI{1845}{\micro\metre}$)
and the detector (at \SI{15.1}{\degree} off-axis) lie safely outside the
$2\theta_0$ emission cone.  No significant fibre stray light reaches the
detector or the waveguide etch region at this placement.

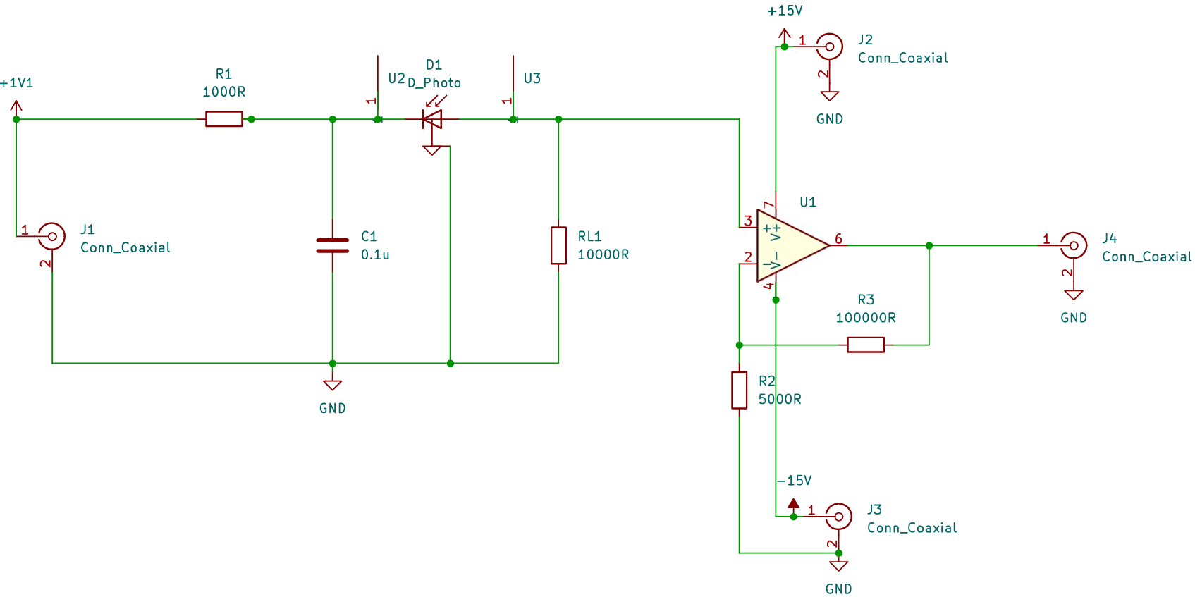
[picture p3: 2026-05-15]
Project_1_On_Chip_Detection/Images/circuit_schematic.png

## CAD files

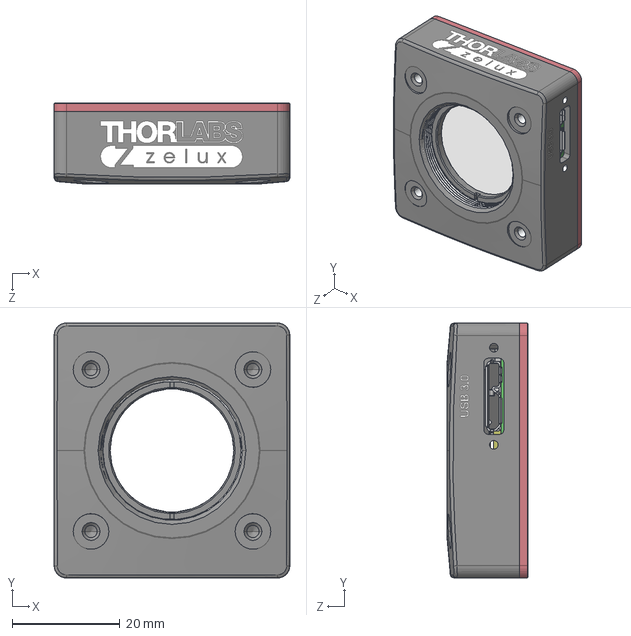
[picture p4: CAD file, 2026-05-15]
Project_1_On_Chip_Detection/solidworks_model/CS165MU-Step.step
43.7 x 47.2 x 15.0 mm

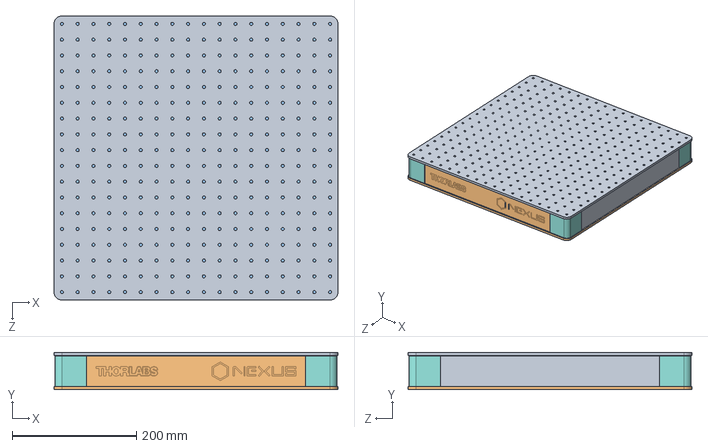
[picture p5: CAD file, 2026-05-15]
Project_1_On_Chip_Detection/solidworks_model/B1818F-Step.step
457.2 x 60.0 x 457.2 mm

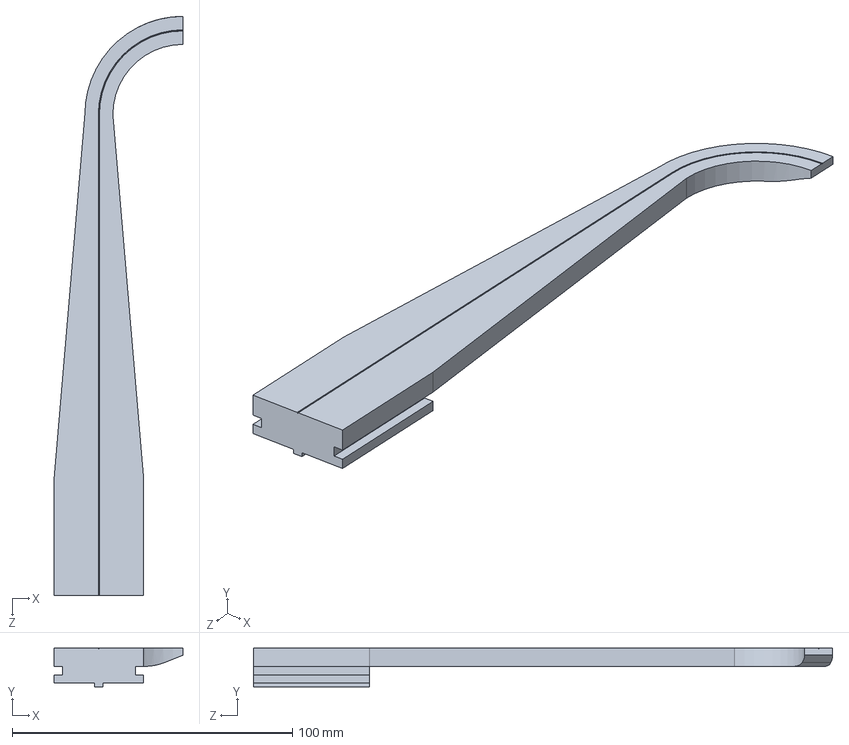
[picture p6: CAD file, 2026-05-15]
Project_1_On_Chip_Detection/Topchip gain integration setup digital twin/top fiber holder.SLDPRT
46.0 x 13.8 x 206.6 mm

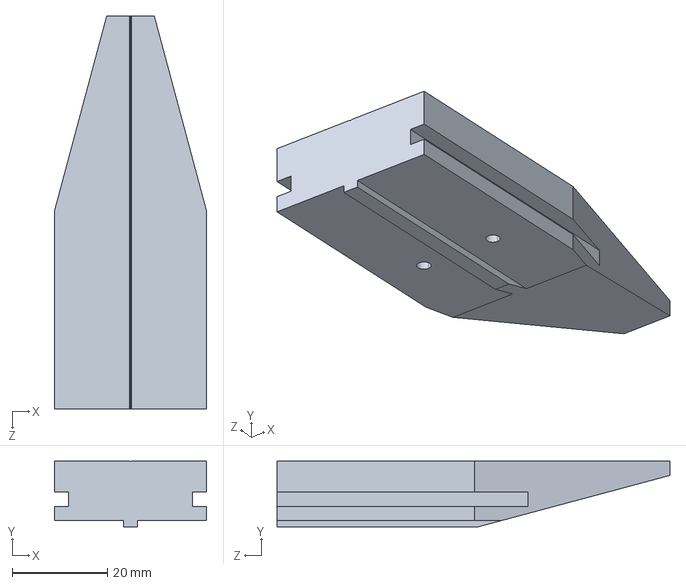
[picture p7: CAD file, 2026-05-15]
Project_1_On_Chip_Detection/solidworks_model/HFV002-Step.step
32.0 x 13.8 x 82.5 mm

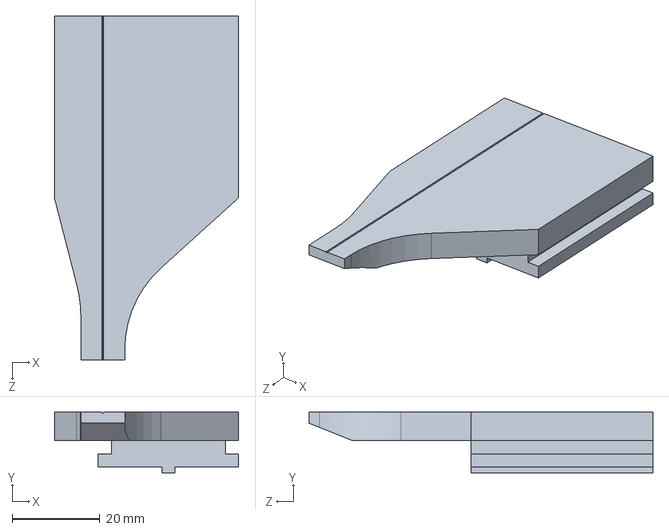
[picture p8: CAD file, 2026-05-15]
Project_1_On_Chip_Detection/Topchip gain integration setup digital twin/bottom fiber holder.SLDPRT
42.0 x 13.8 x 78.4 mm

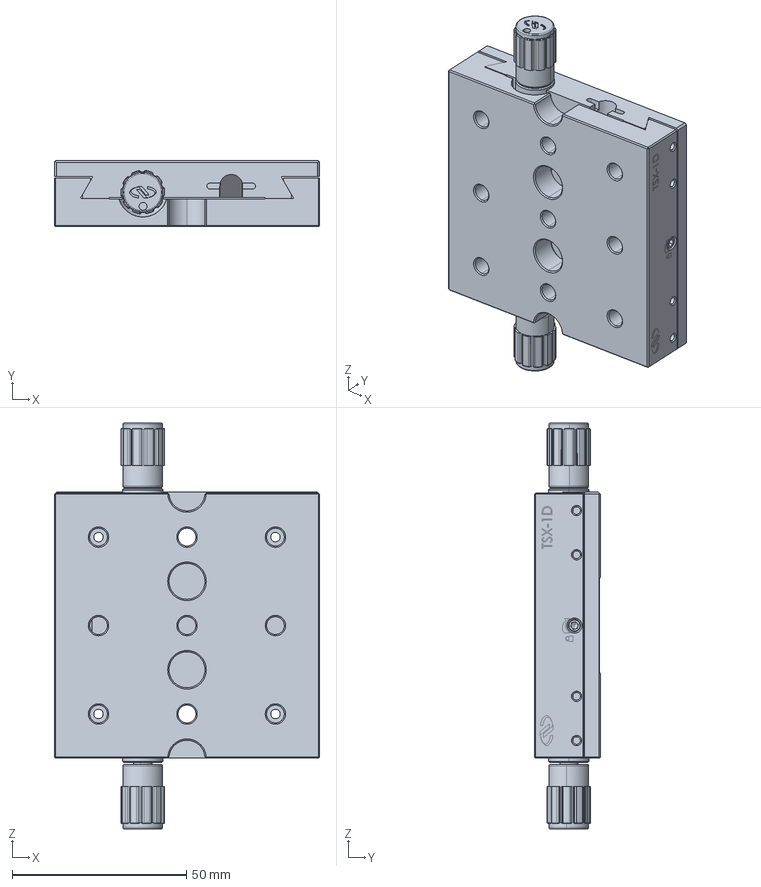
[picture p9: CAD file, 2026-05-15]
Project_1_On_Chip_Detection/solidworks_model/Newport-TSX-1D.stp
76.2 x 19.0 x 116.6 mm

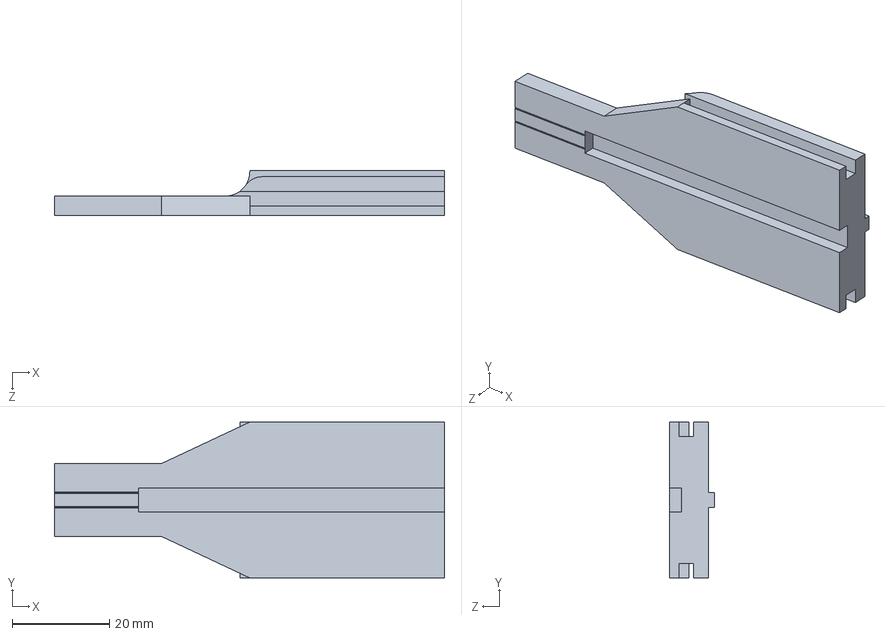
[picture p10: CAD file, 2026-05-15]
Project_1_On_Chip_Detection/Topchip gain integration setup digital twin/topchip_bottom_02_06_26.SLDPRT
80.1 x 32.0 x 9.30 mm

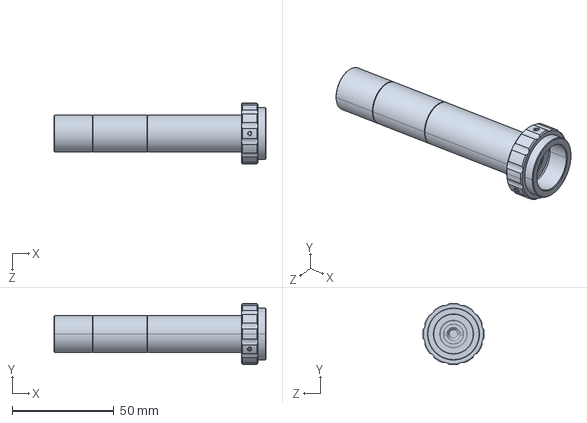
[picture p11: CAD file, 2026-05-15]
Project_1_On_Chip_Detection/solidworks_model/step_63744.step
104.0 x 30.0 x 30.0 mm

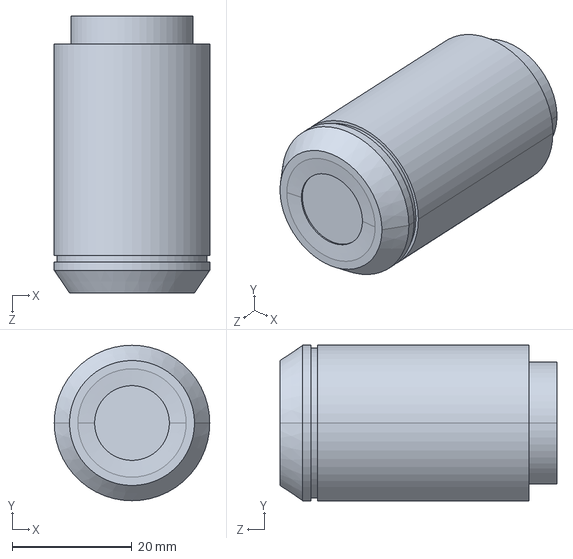
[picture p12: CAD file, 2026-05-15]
Project_1_On_Chip_Detection/Topchip gain integration setup digital twin/step_88206.step
26.0 x 26.0 x 46.3 mm

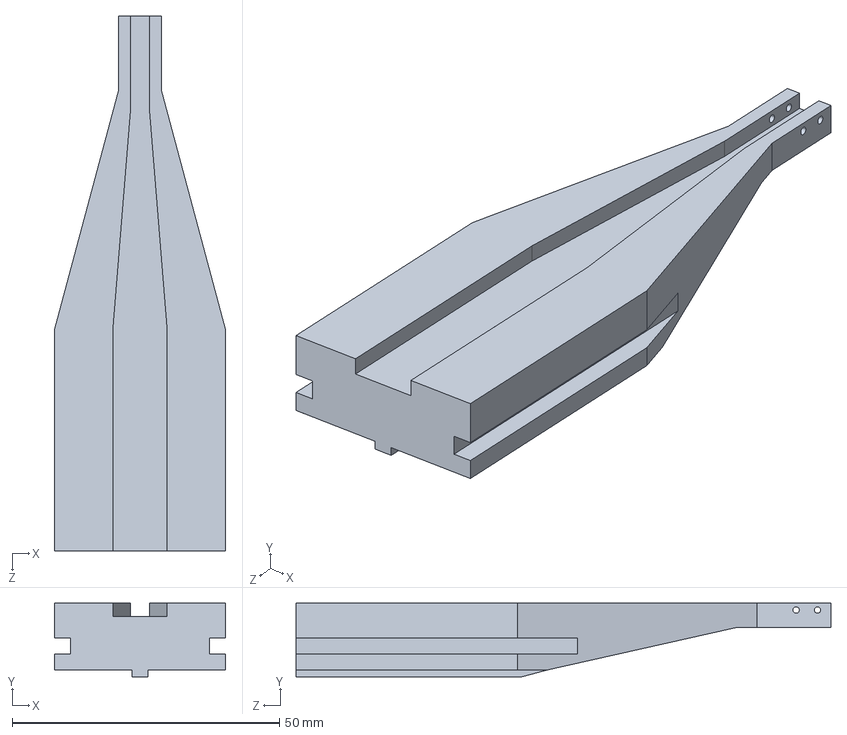
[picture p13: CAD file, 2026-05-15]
Project_1_On_Chip_Detection/solidworks_model/fiber array holder 15_01.STEP
32.0 x 13.8 x 100.1 mm

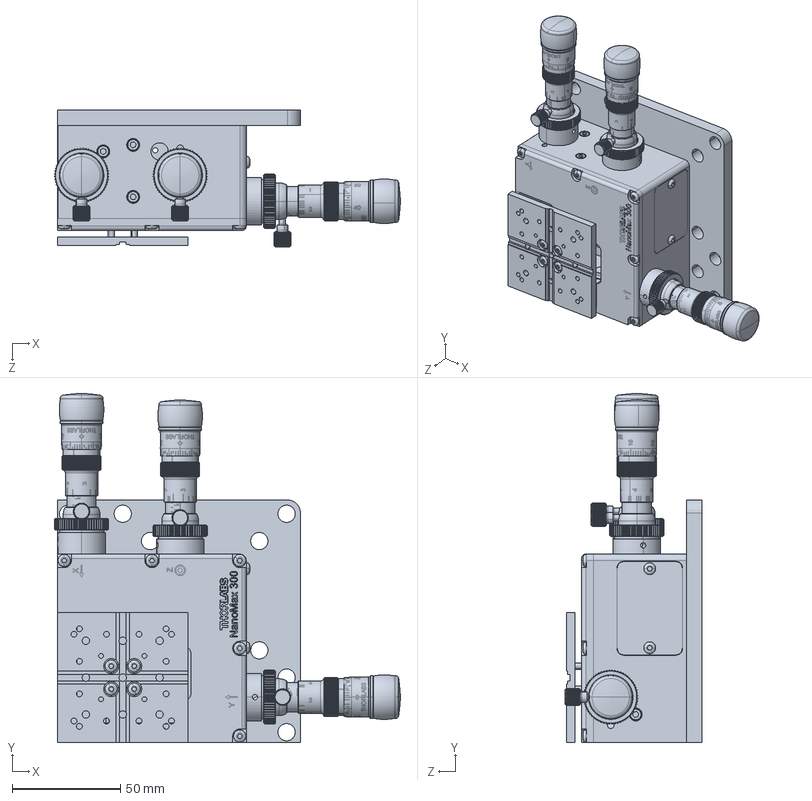
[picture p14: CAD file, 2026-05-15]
Project_1_On_Chip_Detection/Topchip gain integration setup digital twin/MAX313D-Solidworks.sldprt
159.6 x 161.1 x 63.0 mm

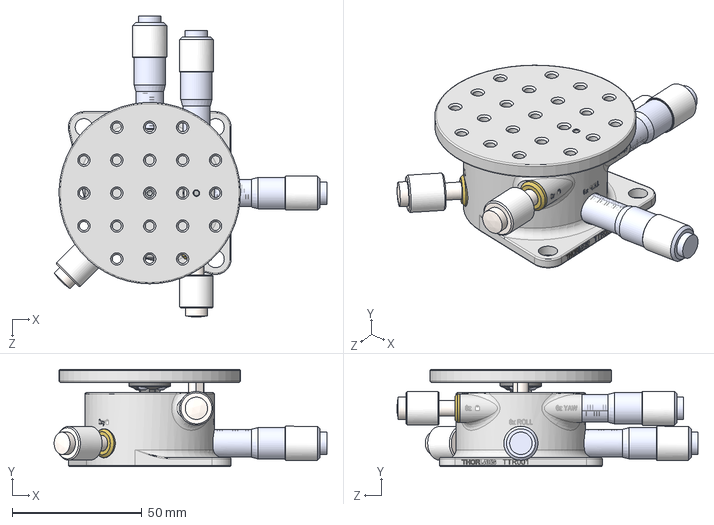
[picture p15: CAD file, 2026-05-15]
Project_1_On_Chip_Detection/solidworks_model/TTR001-Step.step
105.2 x 37.5 x 116.1 mm

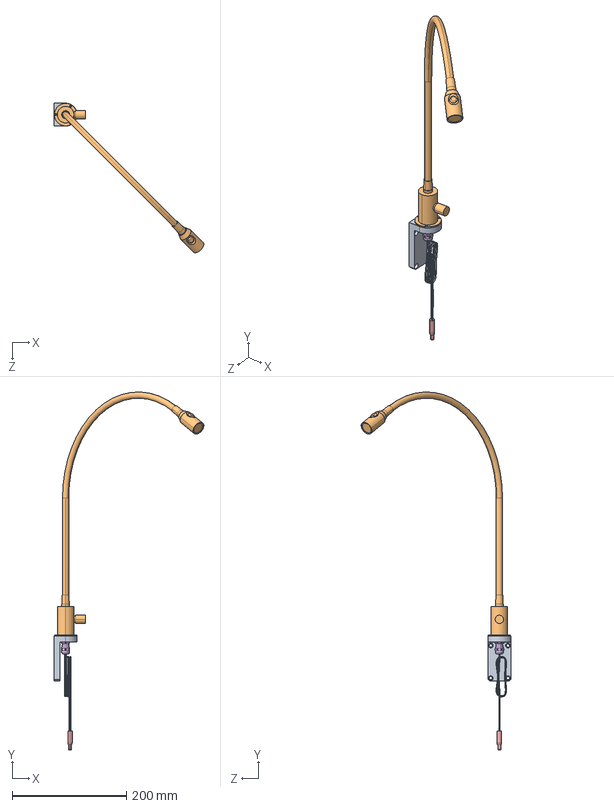
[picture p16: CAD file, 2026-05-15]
Project_1_On_Chip_Detection/solidworks_model/GPXL1-Step.step
262.5 x 627.9 x 262.5 mm
MDS-393
000-109-078_BENT NECK, WIRE HIDDEN
GPXL1 wires
490-PP3-002A
277-13002-ND_Feat_Config

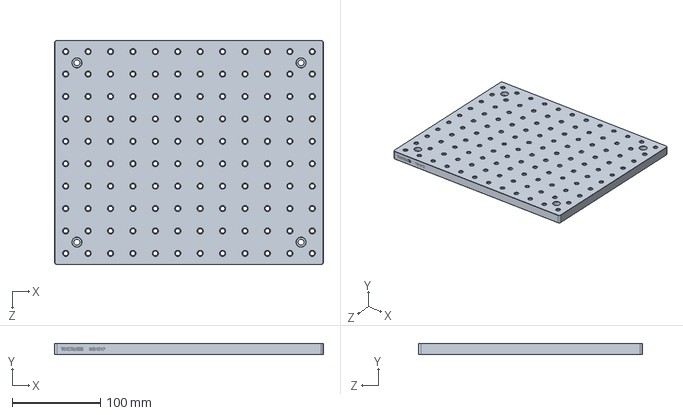
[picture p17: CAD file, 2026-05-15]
Project_1_On_Chip_Detection/Topchip gain integration setup digital twin/MB1012-Solidworks.sldprt
304.8 x 12.7 x 254.0 mm

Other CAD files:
Project_1_On_Chip_Detection/Topchip gain integration setup digital twin/Assem1.SLDASM
Project_1_On_Chip_Detection/Topchip gain integration setup digital twin/Assembly_Feb6.SLDASM
Project_1_On_Chip_Detection/Topchip gain integration setup digital twin/Newport-561D-YZ.sldprt
Project_1_On_Chip_Detection/Topchip gain integration setup digital twin/HFV002-Solidworks.sldprt
Project_1_On_Chip_Detection/Topchip gain integration setup digital twin/Newport-HR-13.sldprt
Project_1_On_Chip_Detection/Topchip gain integration setup digital twin/top fiber holder.STL
Project_1_On_Chip_Detection/Topchip gain integration setup digital twin/topchip_02_04_26.SLDPRT
Project_1_On_Chip_Detection/Topchip gain integration setup digital twin/topchip_02_04_26.STL
Project_1_On_Chip_Detection/Topchip gain integration setup digital twin/topchip_bottom_02_06_26.STL

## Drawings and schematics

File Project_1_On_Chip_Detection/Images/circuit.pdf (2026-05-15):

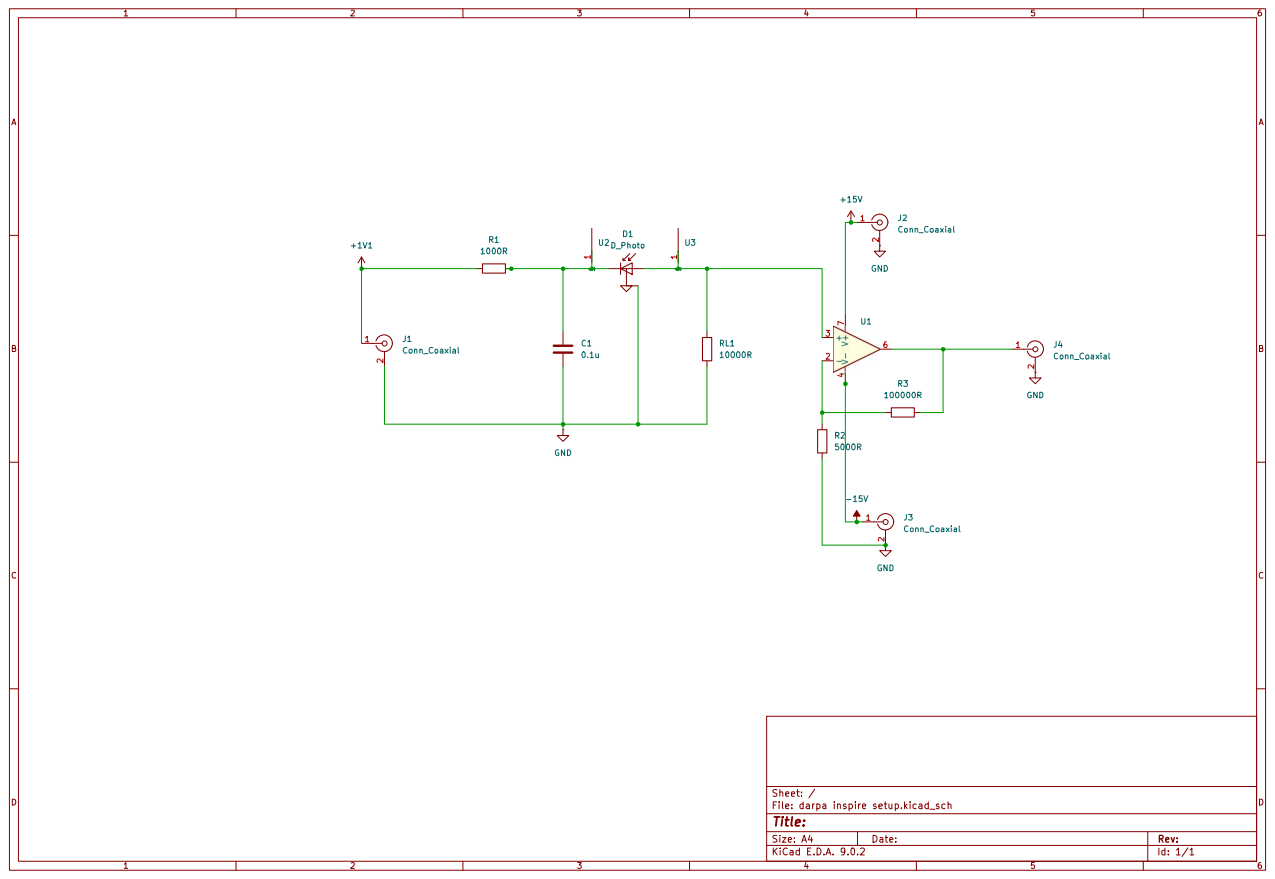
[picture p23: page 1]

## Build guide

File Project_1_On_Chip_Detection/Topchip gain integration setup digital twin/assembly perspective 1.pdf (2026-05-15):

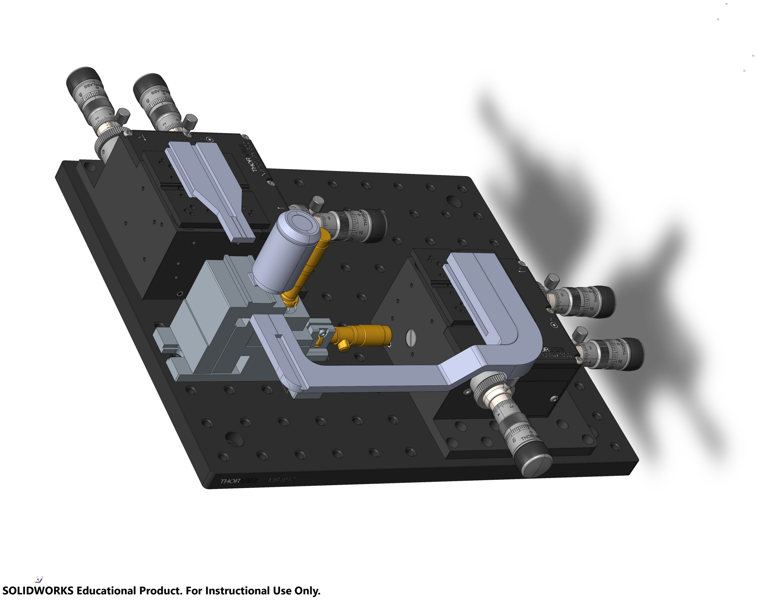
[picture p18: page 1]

SOLIDWORKS Educational Product. For Instructional Use Only.

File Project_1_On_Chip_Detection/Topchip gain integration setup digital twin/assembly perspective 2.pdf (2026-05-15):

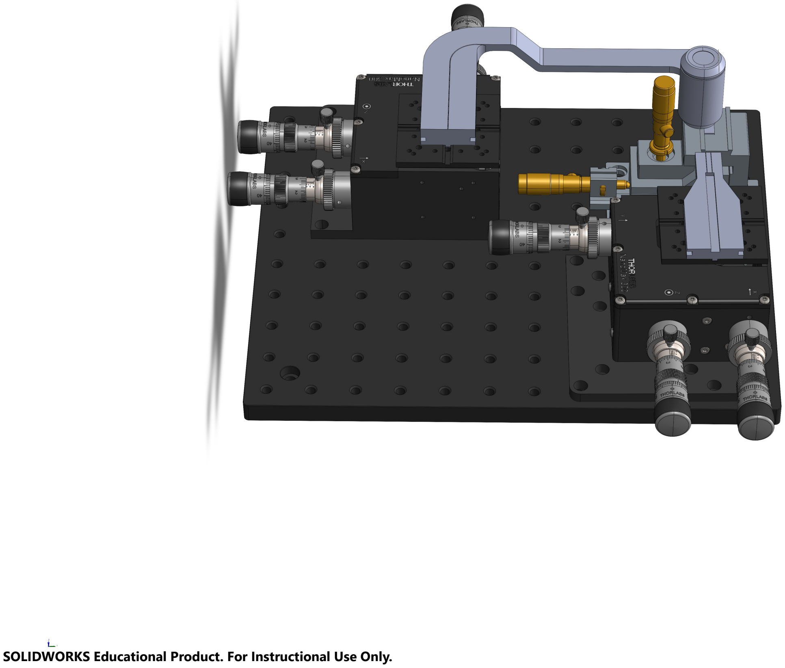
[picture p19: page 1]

SOLIDWORKS Educational Product. For Instructional Use Only.

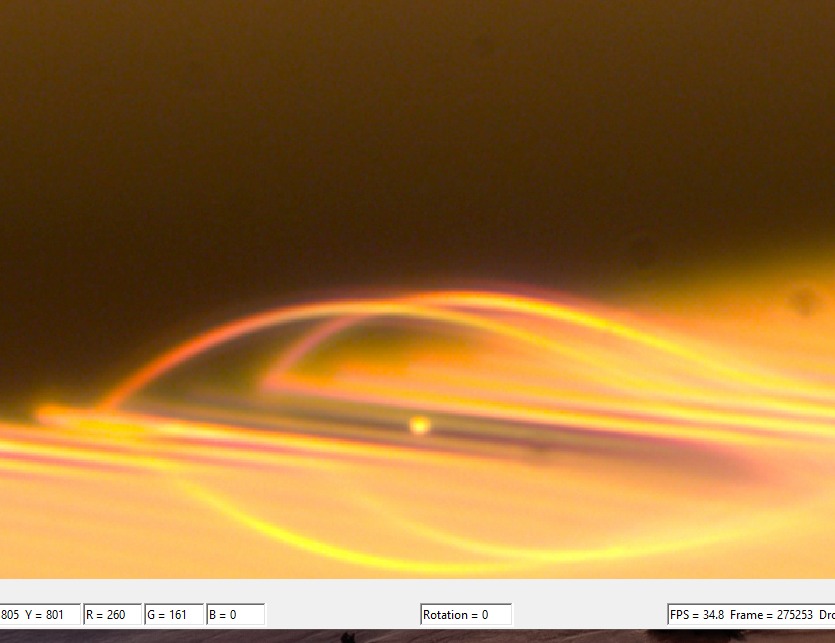
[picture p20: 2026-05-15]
Project_1_On_Chip_Detection/Images/waveguides_zoom.jpeg

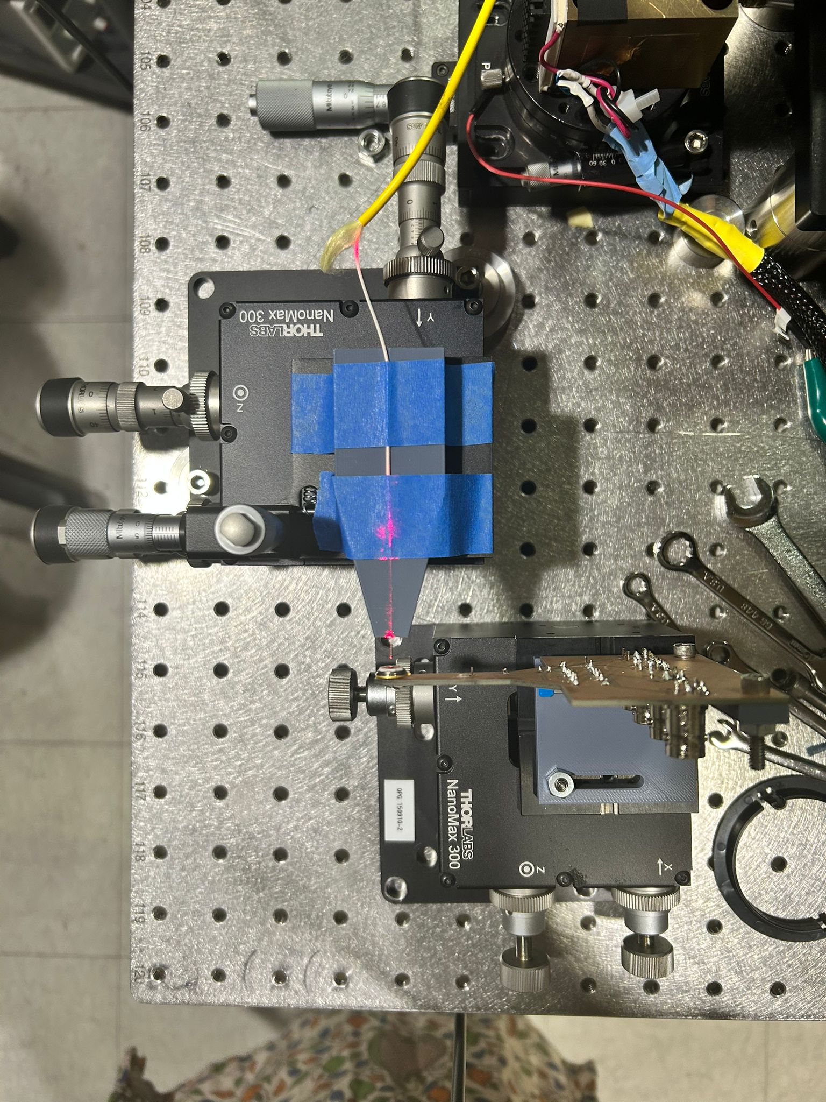
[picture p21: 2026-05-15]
Project_1_On_Chip_Detection/Images/setup_red_light.jpeg

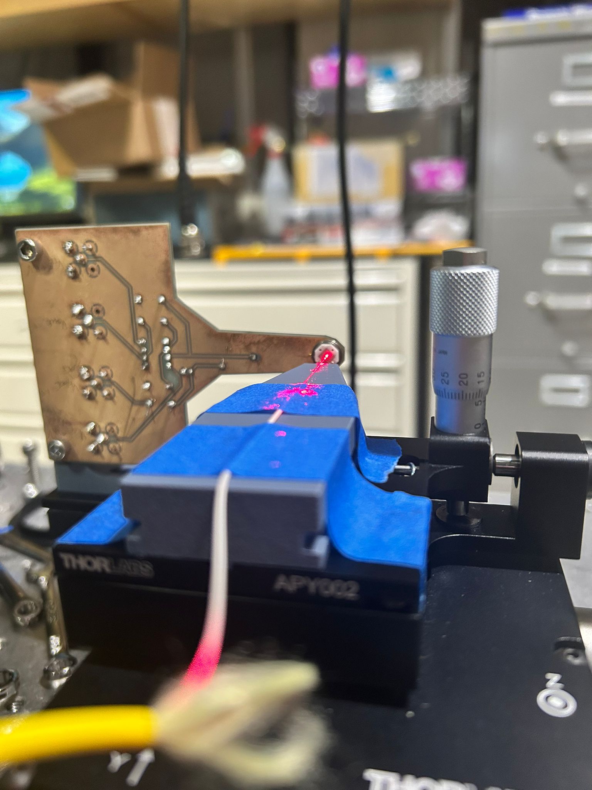
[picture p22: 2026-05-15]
Project_1_On_Chip_Detection/Images/setup_red_light_2.jpeg
